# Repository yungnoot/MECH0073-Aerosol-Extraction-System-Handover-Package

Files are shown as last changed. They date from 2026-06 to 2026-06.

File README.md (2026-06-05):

# MECH0073 — Aerosol Extraction System
*MEng Capstone Group Design Project | UCL Mechanical Engineering 2025–2026*
*In collaboration with Agfa Inkjet Solutions, Cambridge*

Industrial inkjet printers eject droplets at high frequency across a millimetre-scale print gap, 
generating fine airborne satellite ink droplets causing a phenomenon known as ink misting. Left unmanaged, these aerosols contaminate machine internals and cause print defects. 

This project develops an aerosol extraction system that selectively captures low-inertia satellite droplets via downstream suction, 
without disturbing primary drop placement.

The design is underpinned by Euler–Lagrange CFD simulations in OpenFOAM, validated against a reduced-scale experimental rig using  shadowgraphy, and realised as a physical prototype compatible with Agfa printers. 

This repository serves as the central handover package for prototype evaluation and future project continuation. The repository for the simulations and custom OpenFOAM solver can be found in https://github.com/Nolanlau/KinematicDualParcelCloud.

## What's in this repo
- `CAD/` — Assembly and part drawings for the experimental rig and extractor prototype
- `Electronics/` — Arduino sensor control code and wiring schematics
- `Documentation/` — Risk assessments, Bill of Materials, Product Design Specification, and end-of-life plan
- `Reports/` — Final project report

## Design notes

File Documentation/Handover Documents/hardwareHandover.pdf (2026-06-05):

# MECH0073 Experimental Rig and Prototype Handover

Nolan Lau Cze Kai | Tengku Amran Sharif | Goh Teik Beng
| Zhou Yuxiang

### 1. Introduction

This document forms the primary handover record for the Aerosol Extraction System project, developed as part of MECH0073 MEng Capstone Group Design Project. The project aimed to computationally and experimentally investigate printzone aerodynamics in industrial inkjet printers, and to design, manufacture, and test an aerosol extraction system compatible with Agfa Inkjet Solutions’ industrial printers. The project consisted of two hardware deliverables:

1. Experimental Rig — A reduced-scale lab rig for validating computational findings via shadowgraphy.
2. Aerosol Extraction System Prototype — A prototype extractor module designed for integration into Agfa industrial inkjet printers.

The next use of the experimental rig is planned for MECH0085 MSc Individual Project (MSc Engineering with Finance, supervised by Prof. José Rafael Castrejón-Pita), in collaboration with a global agricultural technology company, to investigate the effects of Stokes number and droplet deviation from background flow. The prototype extractor module is also to be held by Prof. José Rafael Castrejón-Pita at the Manufacturing Futures Lab at Marshgate, UCL East for use in a future, follow up student project in collaboration with Agfa Inkjet Solutions.

### 2. Physical Items

2.1. Experimental Rig

The following physical components constitute the experimental rig assembly. Full engineering drawings and a detailed Bill of Materials are provided in Appendix C and Appendix B1 of the MECH0073 final report, respectively, and also at our central handover GitHub repository (https://github.com/yungnoot/MECH0073-Aerosol-Extraction-System-Handover-Package) (a QR code is also available at the end of the document). All items are stored in the Manufacturing Futures Laboratory in Marshgate at UCL East under the care of Prof. José Rafael Castrejón-Pita.

2.2. Aerosol Extraction System Prototype

The following physical components constitute the aerosol extraction system prototype. Full engineering drawings and a detailed Bill of Materials are provided in Appendix D and Appendix B2 of the Final Report, respectively and also at our central handover GitHub repository. (https://github.com/yungnoot/MECH0073-Aerosol-Extraction-System-Handover-Package)

1

2 | N. C. K. Lau and T. A. Sharif and T. B. Goh and Y. X. Zhou

Table 1: Experimental Rig Bill of Materials

Item | Description | Qty
Test Rig Experimental Setup | Full assembly | 1
Test Rig Body | Sub-assembly | 1
Test Rig Experimental Mist Capture
Sub-assembly | 1
PLA 3-Way Profile Connector | 3D-printed frame connector | 2
PLA Height Adj. Platform Rod
Holder
3D-printed platform support | 4
Acrylic Height Adj. Platform Base | Adjustable platform | 1
PLA Experimental Nozzle (S0–S4) 3D-printed, five interchangeable geometries | 5
PLA Vacuum Bleed | 3D-printed bleed body | 1
PLA Test Rig Feet | 3D-printed | 4
Acrylic Test Rig Base | Base plate | 1
RS PRO Aluminium | Profile
20×20 mm
Structural frame extrusion | 2

RS PRO Angle Bracket 20×20 mm,
6 mm groove
Frame connector | 8
Stainless Steel Needle Valve | F-to-F with male adaptors, suction control | 1
Airbrush | with | Compressor
(0.3 mm)
Aerosol generation unit | 1
Conveyor Belt | Substrate drive unit | 1
163 cm Camera Tripod | Camera support | 1
Differential Manometer | Testmeter ETI 9202 | 1
Stainless | Steel | Shims
50×50×1 mm
Print-gap height setting | 10
M4×10 Socket Cap Bolt | Standard fastener (ISO 4762) | 20
M4 Flat Washer | Standard fastener (ISO 7089) | 8
M4 Hex Nut | Standard fastener (ISO 4032) | 16

Project Handover | 3

Table 2: Aerosol Extraction System Prototype Bill of Materials

Item | Description | Qty
Prototype Extractor Module Body | Full assembly | 1
Aluminium Extractor External Frame | Machined aluminium structural frame | 1
PLA Extractor Shape Nozzle (S0– S4) | 3D-printed, five interchangeable inlet geome- tries | 5
PLA Locating Block | 3D-printed nozzle guide blocks | 2
Aluminium Vacuum Pump Connec- tor | Machined channel connector | 1
PLA Electronics Housing | 3D-printed enclosure for electronics | 1
Extractor Gasket | Polymer airtight seal between nozzle and frame | 1
Filter Foam | Replaceable filter medium | 1
Sensirion SDP810-500Pa Differen- tial Pressure Sensor | Digital pressure monitoring; upstream and downstream of filter | 2
OLED Display 77×25.2 mm | Sensor readout display | 1
RS PRO Hookup Wire Roll (PVC, 100 m) | Electronics wiring | 1
RS PRO Straight Through-Hole Pin Headers | Electronics connectors | 1
DHT11 Temperature and Humidity Sensor | Ambient condition monitoring | 1
Arduino Uno Rev3 | Microcontroller for sensor data acquisition and display | 1
Flexible Tubing 10 mm OD | Vacuum ducting between extractor and pump | 1
M5×12 Socket Cap Bolt | Standard fastener (ISO 4762) | 10

2.2.1. Unused Materials and Consumables

Any unused materials from the Bills of Materials listed above are stored in the Manufacturing Futures Laboratory at Marshgate, UCL East. Spare items include, but are not limited to:

- Remaining Aluminium Profiles
- Spare OLED monitor
- Remaining flexible tubing
- Remaining RS PRO hookup wire
- Stainless steel shims
2.3. Technical Documentation

The following documentation is included in the handover package. All digital files are accessible via the central handover GitHub repository. (https://github.com/yungnoot/MECH0073-Aerosol-Extraction-System-Handover-Package)

Table 3: Technical Documentation Index

Document | Format | Location / Reference
Final Project Report | PDF | GitHub repository
Engineering Drawings — Ex- perimental Rig | PDF | Appendix C of Final Report, GitHub repository
Engineering Drawings — Aerosol Extraction System | PDF | Appendix D of Final Report, GitHub repository
CAD Files — Experimental Rig | f3d | GitHub repository
CAD Files — Aerosol Extrac- tion System | f3d | GitHub repository
Bill of Materials — Experi- mental Rig | PDF | Appendix B1 of Final Report, GitHub repository
Bill of Materials — Aerosol Extraction System | PDF | Appendix B2 of Final Report, GitHub repository
Arduino Sensor Source Code | .ino | GitHub repository
OpenFOAM CFD Source Code | Text/shell | GitHub repository (with its own handover docu- ment and documentation repository).
Risk Assessments | PDF | Appendix A of Final Report, OSHENS risk man- agement system, GitHub repository
Experimental Results | jpg/mp4 | GitHub repository

### 3. Operating Instructions

3.1. Experimental Rig Setup
1. Assemble the aluminium profile frame using the 3-way connectors and angle brackets; tighten M4 socket cap bolts finger-tight before final torque.
2. Install the acrylic base and height adjustable platform. Set the print gap height as desired using precision shims placed at multiple spanwise locations. Secure the acrylic ceiling via bolts on the platform rods.
3. Mount the airbrush nozzle flush with the underside of the acrylic ceiling sheet, oriented perpendicular to the substrate, using the retort stand. Fix the nozzle at the print gap centreline.
4. Insert the desired extractor nozzle geometry into the dedicated slot in the downstream acrylic panel.
5. Connect the vacuum cleaner to the bleed body with needle valve in line to regulate suction pressure.
6. Connect the differential manometer to the pressure tap on the extractor body to monitor suction gauge pressure.
7. Start the conveyor belt and allow it to reach steady state before data acquisition. The conveyor is operated at the maximum drive setting throughout all tests.
8. Activate the airbrush compressor. The airbrush spray force should be approximately 21.58 mN, as measured previously via precision scale.
9. Illuminate the printzone using the high-power lighting positioned to maximise contrast for shadowgraphy.
10. Experiments can be recorded by mounting an available camera on the tripod.

Safety: Always turn off the conveyor belt and vacuum when adjusting the extractor or airbrush position. Wear ear protection during prolonged operation. Refer to the MechSpace Risk Assessment (Appendix A2) if uncertain about operational risks before first use.

3.2. Aerosol Extraction System Prototype — Assembly and Integration
1. Slot the desired inlet nozzle piece (S1–S4) into the base of the aluminium frame using the two PLA locating blocks as guides, and bolt into the frame using M3×12 socket cap bolts.
2. Seat filter foam or other filter medium on the interface between the frame and the vacuum pump connector.
3. Bolt the aluminium vacuum pump connector onto the top face of the aluminium frame using M5×12 socket cap bolts.
4. Electronic sensor box comes pre-assembled, but can be easily unbolted to make modifications.
5. Attach the 10mm OD pneumatic tubing from the sensor box into the hole insert in the static fixed jaw, and the 4mm OD into the tap sitting perpendicular on the face of the vacuum connector.
6. Connect the vacuum cleaner to vacuum pump connector, using PVC piping as necessary to extend length as desired.
7. Power electronic sensor box using an appropriate power supply with the provided USB-B to USB-A cable.

### 4. End-of-Life Plan

4.1. Experimental Rig

The experimental rig will be retained at Marshgate, UCL East and reused in the following academic year for MECH0085 MSc Individual Project, supervised by Prof. Castrejón-Pita, in collaboration with a global agricultural technology company. All PLA components are reprintable from the CAD files provided in the GitHub repository should replacement parts be required. Aluminium profile sections and acrylic panels should be stored flat and protected from impact damage.

4.2. Aerosol Extraction System Prototype

The aerosol extraction system prototype will be retained at Marshgate, UCL East for future student projects in collaboration with Agfa Inkjet Solutions. Transfer of prototype has been organised with Prof. Castrejón-Pita to be moved to the Manufacturing Futures Laboratory at Marshgate, UCL East after the 2026 Mechanical Engineering Summer Session. The Open-FOAM computational model is available on GitHub for use in future student projects, and comes with a separate handover document as part of the handover package.

4.3. Disposal of Materials
- PLA offcuts and failed prints are disposed of in the PLA recycling bin on the 5th Floor workshop inside MechSpace.
- Acrylic sheets that are unsuitable for reuse are disposed of in the appropriate recycling bins.

### 5. Key Contacts

For queries relating to the project, rig, or prototype, contact the relevant parties listed below.

Table 4: Key Project Contacts

Role | Name | Contact
Project Supervisor | Prof. | José | Rafael
Castrejón-Pita

r.pita@ucl.ac.uk

Team Member | Teik Beng Goh | derrick.goh.22@alumni.ucl.ac.uk
Team Member | Nolan Lau Cze Kai | nolan.lau.22@alumni.ucl.ac.uk
Team Member | Tengku Amran Sharif | amran.sadruddin.22@alumni.ucl.ac.uk
Team Member | Yuxiang Zhou | yuxiang.zhou.22@alumni.ucl.ac.uk

### 6. Declarations

This handover document has been prepared by the Aerosol Extraction System group as a component of the MECH0073 prototype handover package. The team confirms that:

- All physical items listed in Section 2 are present and accounted for in the designated storage space provided by Prof. José Rafael Castrejón-Pita at the Manufacturing Futures Laboratory at Marshgate, UCL East.
- All documentation listed in Section 2.3 has been submitted and is accessible via the project GitHub repository.
- All risk assessments are fully signed off and available in Appendix A of the Final Report, on the OSHENS risk management system, and the central GitHub repository accessible via QR code below.

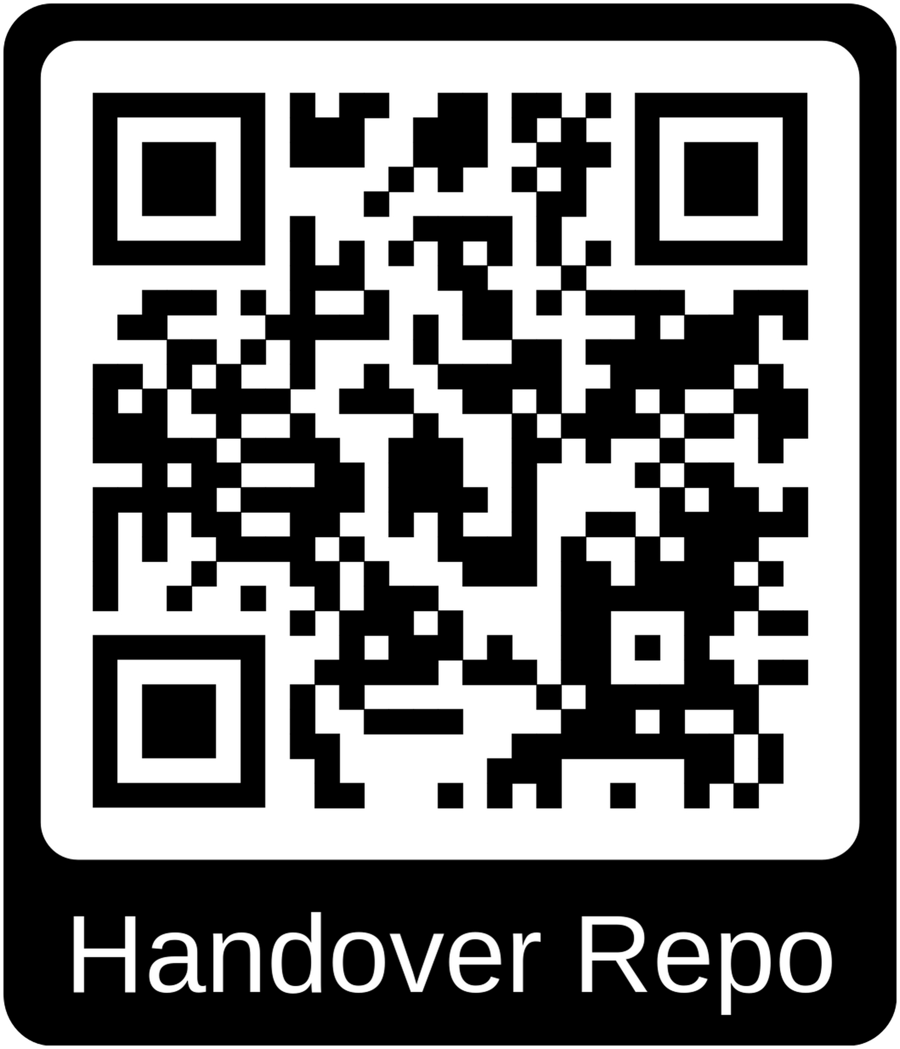
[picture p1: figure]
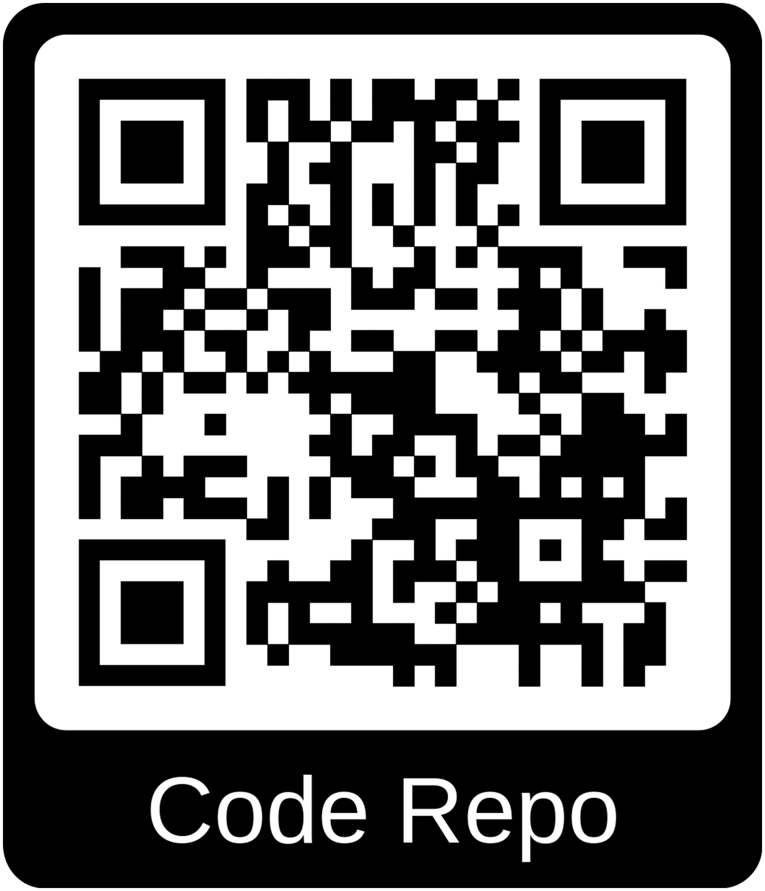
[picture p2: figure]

Figure 1: Handover Repository QR Code | Figure 2: Code Repository QR Code

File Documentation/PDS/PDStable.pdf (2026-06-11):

Table 1: Product design specification for the aerosol extraction system prototype framed as Functions, Objectives, and Constraints (FOC) (extracted from final report).

Category | Requirement | Specification
Functions | Mist Extraction | • Remove airborne low-inertia satellite droplets and ink mist from the printzone during operation via downstream suction.
| Selective Action | • Preferentially entrain low-inertia satellite droplets while leaving the trajectories of the main printing droplets ef- fectively unchanged.
| Continuous Operation | • Operate continuously over typical industrial print dura- tions without loss of basic functionality.
| Flow Regulation | • Allow for the adjustment of suction pressure to tune for specific situations, accompanied by active differential pressure measurement.
| Condition Monitoring | • Monitor ambient temperature and relative humidity for experimental characterisation, and provide indicators of degraded operating conditions (e.g., pressure changes due to filter loading).
Objectives | Extraction Efficiency | • Achieve a high capture rate of airborne mist-forming satellites, targeting a 50% capture rate corresponding to 20 g/s. • Actual performance can be gauged by the darkening of a HEPA filter.
| Suction Strength | • Minimise pressure drop or losses across the system to ensure operating efficiency.
| Maintainability | • Provide straightforward access for the cleaning of de- posited ink and the rapid replacement of filters or in- ternal flow components.
| Assembly Simplicity | • Minimise the number of parts with interchangeable parts, enabling straightforward assembly and installation using simple fasteners (e.g., bolts).
| Manufacture Simplicity | • The design should be easily manufactured using access- ible methods like additive manufacturing, machining and standard workshop fabrication.
| Modularity | • Ensure design elements (e.g., extractor geometry, elec- tronics) are easily swappable and expandable to allow for rapid iteration and future improvements.

1

Table 1: Product design specification for the aerosol extraction system prototype framed as Functions, Objectives, and Constraints (continued).

Category | Requirement | Specification
Constraints | Geometric
Limits
- The system must conform to a maximum bounding box of 770 mm × 170 mm × 750 mm (free space available in printers).

Spatial
Compatibility
- The extractor must maintain clearance for the printgap and absolutely must not obstruct printheads, sensors, maintenance access points, or other critical printer subsystems.
Capture Zone | • The extractor inlet geometry must possess a sufficiently
large capture zone of 350 mm in length to cover the working area of the printhead.

Material
Integrity
- Materials must be sufficiently stiff to maintain alignment and stability during operation.
- Prolonged exposure to inks must not lead to significant chemical degradation (though superficial aesthetic staining is acceptable).

Electrical Safety • Any electronics used for sensing or monitoring must operate safely at low voltages and be suitable for safe integration into a prototype system.

2

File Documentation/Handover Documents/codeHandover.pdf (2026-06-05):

# Conducting Euler-Lagrange Particle Coupled Fluid Dynamics Simulations on OpenFOAM

Nolan Lau Cze Kai | Tengku Amran Sharif | Goh Teik Beng
| Zhou Yuxiang

### 1. Introduction

Our simulations involved simulating inkjet printing which involved ejected ink particles moving within air. This is a multiphase situation due to the liquid and gas phase involved. Our approach leveraged on the assumption that as the inks are water-based, the capillary length in air would be approximately 2.7 mm (Rapp, 2017), and thus much larger than the droplet diameters which are of μm size. This allowed us to assume that the ink droplets behaved as rigid spheres in air, adopting a Lagrangian approach for the ink droplets. We conducted our simulations in OpenFOAM (Weller et al., 1998). Due to our specific requirements, a proprietary solver coined as kinematicDualParcelFoam was programmed and used and is publicly accessible on GitHub (https://github.com/Nolanlau/KinematicDualParcelCloud) (Lau, 2026). The GitHub also includes an example case for reference. This document will be primarily based on the use of the aforementioned solver. Use of the solver expects experience and understanding in computational fluid dynamics (CFD) and is far beyond the scope of someone who has only followed a guided tutorial before.

### 2. Hardware and Software Prerequisites

The computationally demanding nature of computational fluid dynamics (CFD) simulations necessitates suitable computational hardware other than for small validation cases. As a minimum recommendation, local execution should employ:

1. a modern multi-core CPU (preferably ≥ 8 physical cores),
2. at least 16–32 GB RAM,
3. and a solid-state drive (SSD).

The simulations are predominantly CPU-bound rather than GPU-bound, as OpenFOAM does not natively exploit GPU acceleration in standard configurations. Furthermore, OpenFOAM works only in Linux environments.
The recommended execution environments are therefore:
1. Windows Subsystem for Linux (WSL2) on Windows,
2. UCL Kathleen HPC Cluster,
3. UCL Myriad HPC Cluster.

The UCL high performance computing (HPC) clusters are especially recommended for bulk work particularly UCL Kathleen HPC Cluster (https://www.rc.ucl.ac.uk/docs/Clusters/Kathleen/) and UCL Myriad HPC Cluster. (https://www.rc.ucl.ac.uk/docs/Clusters/Myriad/) Students can apply for access with the sponsorship of a permanent staff.

1

2 | N. C. K. Lau and T. A. Sharif and T. B. Goh and Y. X. Zhou
2.1. OpenFOAM Environment

The simulations are conducted using OpenFOAM, an open-source finite volume CFD framework written primarily for Linux-based operating systems. OpenFOAM is not natively supported under standard Windows environments and therefore requires either:

1. a Linux operating system (including through a virtual machine),
2. Windows Subsystem for Linux (WSL2),
3. or execution through a remote Linux HPC cluster (e.g., UCL Myriad).
| The recommended OpenFOAM version for this project is OpenFOAM® v2112 as the
custom solver was developed for this release. We have found OpenFOAM® v2312 to work as well. Compatibility with older versions is poor but newer versions are likely to work. If installing on a private system, the installation guide (https://gitlab.com/openfoam/core/openfoam/-/wikis/precompiled) should be consulted. UCL Myriad and Kathleen already carry several versions of OpenFOAM.
| The OpenFOAM tutorial cases distributed with the software as well as additional docu-
mentation online are highly recommended for familiarisation with:
1. theoretical basis of finite volume method (FVM)
2. mesh generation,
3. solver execution,
4. multiphase flow,
5. and lagrangian particle tracking.
2.1.1. Local Installation Using WSL2

For users operating on Windows systems, the recommended approach is to install Ubuntu Linux through Windows Subsystem for Linux 2 (WSL2). This provides a near-native Linux environment while retaining standard Windows usability. Microsoft provides installation instructions. (https://learn.microsoft.com/en-us/windows/wsl/install)
| Ubuntu 22.04 LTS is recommended for compatibility with OpenFOAM-v2212. General
Linux familiarity, including use of the shell, bash scripting, SSH and file permissions is assumed for effective use of OpenFOAM and the HPC clusters.
| You should be highly familiar with the use of OpenFOAM before proceeding further.

Euler-Lagrange Particle Coupled Simulations Fluid Dynamics | 3

### 3. Solver kinematicDualParcelFoam

The custom solver kinematicDualParcelFoam was adapted from the standard OpenFOAM solver kinematicParcelFoam and shares close similarities. The main difference is that within the functional class of cloud, the base solver, kinematicParcelFoam only has a singular cloud (kinematicDualParcelFoam) whereas the custom solver has two (mainCloud and satelliteCloud). This allows for the simultaneous evolutions of two different types of particles which may have different properties in a single simulation.

3.1. Governing Equations

The computational model adopts an Euler–Lagrange formulation. The carrier phase, namely air, is treated as a continuum and solved on an Eulerian mesh, while droplets are tracked as discrete Lagrangian particles. This approach is well suited to particle-laden flows in which the dispersed phase occupies a small volume fraction but may still exchange momentum with the carrier phase.
The carrier phase is treated as an incompressible Newtonian fluid with the incompressible Navier-Stokes equation solved in the Eulerian frame as
∇ ⋅ u = 0, | (1)

Du
Dt

= −

1
ρ
∇p + ν∇²u + S, | (2)

where u represents fluid velocity, p is pressure, ρ and ν are the fluid density and kinematic viscosity respectively. The source term, S represents the momentum coupling from the Lagrangian phase, accounting for the impulse transfer from the particles to the fluid. The translational motion of the spherical particles are described by the trajectory equation and Newton’s Second Law,
dxP
dt
= uP, | (3)

mP

duP
dt

= Fd + Fg

, | (4)

where xP and uP represent the position and velocity of the particle respectively while the particle mass is calculated as

mP = ρP

πD³
P
6
, | (5)

being a uniform sphere, where ρP represents the particle density and DP is the particle diameter. The drag force term Fd
is calculated using the sphere drag correlations by Putnam (1961) as

Fd = Cd

πD²
P
8
ρ(u − uP)|u − uP|, | (6)

where the drag coefficient, Cd

is calculated using the local particle Reynolds number, ReP as
Cd = { ²⁴
ReP

(1 + 1

6Re²/3
P

) if ReP ≤ 1000
0.424 | if ReP > 1000
. | (7)

The gravity force term is calculated as

Fg = mPg (1 − ρ
ρP
) , | (8)

where g is the gravitational acceleration vector.
For the present application, additional force contributions such as virtual mass and pressuregradient effects are small in comparison with drag and gravity and are therefore neglected. However, additional forces may be customised or enabled in the simulation to change (4) as desired. The Euler–Lagrange framework is particularly useful because it permits direct modelling of the force coupling between primary droplets and the carrier flow, while also allowing a large population of secondary droplets to be tracked efficiently.
3.2. Compilation Instructions

The custom solver can be compiled and installed to your version of OpenFOAM using the instructions in the GitHub. (https://github.com/Nolanlau/KinematicDualParcelCloud/blob/main/README.md) However, the OpenFOAM base files are not modifiable in the UCL HPC. Instead, the solver will have to be compiled within your scratch and invoked through its path on scratch.

### 4. Running Simulations

This section describes the general workflow for preparing and executing simulations using the custom kinematicDualParcelFoam solver. The workflow consists broadly of:

1. mesh generation,
2. configuration of the Eulerian flow solver,
3. configuration of the Lagrangian particle clouds,
4. parallel decomposition,
5. solver execution,
6. and post-processing.

In the OpenFOAM idiom, a simulation is enclosed within a case which is a folder consisting of settings and where results will be stored upon execution. An example case using the solver is provided within the GitHub. (https://github.com/Nolanlau/KinematicDualParcelCloud)

4.1. Case Structure

OpenFOAM cases generally follow the directory structure:

case/
0/
constant/
system/

The purpose of each directory is:

1. 0/: Initial and boundary conditions,
2. constant/: Mesh, material properties, and cloud settings,
3. system/: Numerical schemes and solver controls.

4.2. Mesh Generation

The computational mesh is generated prior to simulation execution. The example case within the GitHub (https://github.com/Nolanlau/KinematicDualParcelCloud) contains a functioning mesh. When creating a mesh for your specific purposes, to ensure highly reproducible and iterative workflows, we suggest the use of parametric mesh generation scripts written in MATLAB (or other programming language).

4.2.1. Parametric blockMeshDict Generation

For simple block-structured geometries, OpenFOAM employs the blockMesh utility. Its configuration is natively defined in a dictionary within system/blockMeshDict. For small changes from the mesh provided in the example case, the corresponding blockMeshDict may be manually modified. For more extensive studies, we recommend the use of a MAT-LAB script to parametrically write the blockMeshDict dictionary file so that the geometric properties can be easily changed. Once the MATLAB script writes the blockMeshDict to the system/ directory, the mesh is generated natively in OpenFOAM by running:

blockMesh

4.2.2. Parametric Gmsh Mesh Generation

For more complex geometries (e.g., non-orthogonal or spline boundaries), we recommend the use of Gmsh (https://gmsh.info/) for the creation of unstructured meshes (Geuzaine & Remacle, 2009). A similar script should be used to write a dictionary ’.geo’ file. We then execute Gmsh from the terminal to create a 3D mesh exported in the ‘.msh‘ format:

gmsh -3 <name>.geo -format msh2

Finally, the mesh is converted to OpenFOAM format via the built-in utility:

gmshToFoam <name>.msh

Regardless of the approach employed (native blockMesh or Gmsh), the computational mesh quality should subsequently be verified using:

checkMesh

for low mesh non-orthogonality particularly if complex geometry is involved.

4.3. Initial and Boundary Conditions

The initial and boundary conditions are specified within the 0/ directory. Common files include:

0/U
0/p

The velocity field file (U) specifies velocity boundary conditions and the initial field. It will come to taken on the global velocity field in later time steps. The moving substrate is typically implemented using a Dirichlet boundary condition

type | fixedValue;
value | uniform ( 1 0 0 );

while inlets and outlets take on

type | zeroGradient;

and walls take on the no slip condition as

type | noSlip;

The pressure field file (p) specifies pressure boundary conditions. Inlets and outlets have their pressures specified as desired. Atmospheric boundaries are specifically specified as zero gauge pressure as

type | fixedValue;
value | uniform 0;

while walls have

type | zeroGradient;
4.4. Lagrangian Particle Clouds

The custom solver supports two particle clouds:

1. a coupled primary cloud,
2. and an uncoupled secondary cloud.

The primary cloud represents the larger ballistic droplets responsible for printing and exchanges momentum with the carrier phase. The secondary cloud represents smaller satellite droplets which behave approximately as passive tracers and do not contribute appreciably to the momentum source term.
Cloud properties are generally specified within:

constant/
mainCloudProperties
satelliteCloudProperties

or equivalent cloud configuration dictionaries. Typical parameters include:

1. particle diameter,
2. density,
3. injection velocity,
4. parcel count,

5. injection location,
6. drag law,
7. and interaction models.

A simplified example is:

solution
{
active | yes;
coupled | yes;
transient | yes;
}

constantProperties
{
rho0 | 1000;
}

subModels
{
particleForces
{
sphereDrag;
}

injectionModels
{
model1
{
type | patchInjection;
patchName | nozzlePatch;
U0 | (0 -10 0);
parcelsPerSecond 100000;
duration | 1;
flowRateProfile constant 1; sizeDistribution
{
type fixedValue;
fixedValueDistribution
{
value 22e-6;
}
}
}
}

}

Note that the secondary cloud, satelliteCloud does not contribute a source term to the momentum equation in (2) so toggling

coupled no;

is redundant. However, the solver could be modified to have both clouds contributing momentum source terms whereupon they could be separately toggled on and off.

4.5. Numerical Controls

The primary numerical controls are contained within:

system/controlDict
system/fvSchemes
system/fvSolution

The timestep is constrained using the Courant number:

adjustTimeStep yes;
maxCo | 0.5;

Transient simulations involving particle injection generally require small timesteps owing to high particle velocities and small mesh scales. Furthermore, OpenFOAM only natively supports first-order Euler method time-stepping for particle motion.

4.6. Running Simulations Locally

After mesh generation and case setup, the simulation may be executed serially using:

kinematicDualParcelFoam

For parallel execution using 8 cores:

decomposePar
mpirun -np 8 kinematicDualParcelFoam -parallel

After completion:

reconstructPar

The decomposition settings are specified in:

system/decomposeParDict

An example configuration for decomposition into 8 subdomain for 8 cores is:

numberOfSubdomains 8;

method scotch;

4.7. Running Simulations on UCL HPC Clusters

Large simulations should be executed through the UCL HPC batch scheduling system. Before execution, the appropriate software environment must be loaded:

module load beta-modules
module unload gcc-libs
module load gcc-libs/7.3.0
module unload compilers
module load compilers/gnu/7.3.0
module unload mpi
module load mpi/openmpi/3.1.4/gnu-7.3.0 module load openfoamplus/v2112/gnu-7.3.0-64

A typical submission script is shown below.

4.7.1. Example HPC Submission Script

#!/bin/bash -l

#$ -S /bin/bash

#$ -l h_rt=24:00:0

#$ -l mem=1G

#$ -N test

#$ -pe mpi 7

#$ -wd /myriadfs/home/<user>/Scratch/test

module load beta-modules

module unload gcc-libs
module load gcc-libs/7.3.0

module unload compilers
module load compilers/gnu/7.3.0

module unload mpi
module load mpi/openmpi/3.1.4/gnu-7.3.0

module load openfoamplus/v2112/gnu-7.3.0-64

source $WM_PROJECT_DIR/etc/bashrc

blockMesh

decomposePar -force

gerun \
/myriadfs/home/<userID>/Scratch/kinematicDualParcelFoam/kinematicDualParcelFoam \ -parallel
reconstructPar

10 | N. C. K. Lau and T. A. Sharif and T. B. Goh and Y. X. Zhou

rm -r processor*

4.8. Submitting Jobs

The script may be submitted using:

| qsub submit.sh
| Job status may be monitored using:

qstat

| A job may be terminated with:
| qdel <jobID>
4.9. Post-Processing

Simulation results may be visualised using ParaView:

paraFoam

Note that while 3D visualisation is supposedly possible using UCL HPC Clusters with an X server, we have found this unreliable. We recommend doing 3D post-processing with ParaView locally on your personal computer.

References

Geuzaine, C., & Remacle, J.-F. (2009). Gmsh: A 3-D finite element mesh generator with built-
| in pre- and post-processing facilities. International Journal for Numerical Methods in Engineering, 79(11), 1309–1331. https://doi.org/10.1002/nme.2579

Lau, N. C. K. (2026). kinematicDualParcelFoam. Retrieved February 7, 2026, from https:
| //github.com/Nolanlau/KinematicDualParcelCloud/tree/main
Putnam, A. (1961). Integratable form of droplet drag coefficient. Journal of the American
| Rocket Society, 31(10), 1467–1468.
Rapp, B. E. (2017). Chapter 21 - capillarity. In B. E. Rapp (Ed.), Microfluidics: Modelling,
| Mechanics and Mathematics (pp. 445–451). Elsevier. https://doi.org/10.1016/B978- 1-4557-3141-1.50021-6 (https://doi.org/10.1016/B978-1-4557-3141-1.50021-6)

Weller, H. G., Tabor, G., Jasak, H., & Fureby, C. (1998). A tensorial approach to computa-
| tional continuum mechanics using object-oriented techniques. Computer in Physics, 12(6), 620–631. https://doi.org/10.1063/1.168744

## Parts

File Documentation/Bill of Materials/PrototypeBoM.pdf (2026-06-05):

# BILL OF MATERIALS

PROJECT REF: | 547908
Project | Bom Section | UID | Issue Revision | Type | Part Description | Part Number | Quantity | Layout | 3D | 2D | Density Mass Each
547908 | 00 | 0000 | 01 | B | Assembly | Prototype Extractor Module Body | 547908-00-0000-01B | 1 | g | g | g | 0 | 0.000
547909 | 01 | 0001 | 01 | A | Assembly | Extractor Electronic Integration | 547909-01-0001-01A | 1 | g | g | g
547908 | 02 | 0002 | 01 | A | Assembly | Video/Image Recording Setup | 547908-02-0002-01A | 1 | g | g | g | 0
547908 | 00 | 0003 | 01 | B | Part | Aluminium Extractor External Frame | 547908-00-0003-01B | 1 | g | g | g | 2700 | 1.264
547908 | 00 | 0004 | 01 | B | Part | PLA Extractor Shape Nozzle | 547908-00-0004-01B | 5 | g | g | g | 1250 | 0.878
547908 | 00 | 0005 | 01 | A | Part | PLA Locating Block | 547908-00-0005-01A | 2 | g | g | g | 1250 | 0.078
547908 | 00 | 0006 | 01 | A | Part | Aluminium Mounting Bracket | 547908-00-0006-01A | 2 | g | g | g | 2700 | 0.105
547908 | 00 | 0007 | 01 | A | Part | Aluminium Extractor Vacuum Connector | 547908-00-0007-01A | 1 | g | g | g | 1250 | 0.273
547908 | 01 | 0008 | 01 | A | Part | PLA Electronics Housing | 547908-01-0008-01A | 1 | g | g | g | 1250 | 0.086
547908 | 01 | 0009 | 01 | A | Part | Alumnium Electronics Housing Bracket | 547908-01-0009-01A | 2 | g | g | g | 2700 | 0.003
547908 | 00 | 0010 | 01 | A | Part | Extractor Gasket | 547908-00-0010-01A | 1 | g | g | g | 1380 | 0.391
547908 | 00 | 0011 | 01 | A | Procurement 300 x 1200 mm PM2.5 HEPA Filter Paper with 20 mm Folds | 547908-00-0011-01A | 1 | G | g | g | 0 | 0.040
547908 | 01 | 0012 | 01 | A | Procurement Sensiron Pressure sensor (+- 500Pa) | 547908-01-0012-01A | 2 | g | g | g | 0 | 0.000
547908 | 01 | 0013 | 01 | A | Procurement 2.42 Inch SSD1309 128 x 64 OLED Display | 547908-01-0013-01A | 1 | g | g | g | 0 | 0.015
547908 | 01 | 0014 | 01 | A | Procurement RS PRO PVC 100m Hookup Wire Roll | 547908-01-0014-01A | 0.01 | g | g | g | 0 | 0.060
547908 | 01 | 0015 | 01 | A | Procurement RS PRO Straight Through Hole Pin Headers | 547908-01-0015-01A | 1 | g | g | g | 0 | 0.022
547908 | 01 | 0016 | 01 | A | Procurement DHT11 Module (Temperature and Humidity sensor) | 547908-01-0016-01A | 1 | g | g | g | 0 | 1.000
547908 | 01 | 0017 | 01 | A | Procurement Arduino UNO Rev 3 | 547908-01-0017-01A | 1 | g | g | g | 0 | 0.004
547908 | 02 | 0018 | 01 | A | Procurement 163cm Camera Tripod | 547908-02-0018-01A | 1 | g | g | g | n | 1.150
547908 | 00 | 0019 | 01 | A | Procurement RS PRO Polyvinyl Chloride Flexible Tubing 6mm OD | 547908-00-0019-01A | 1 | g | g | g | 1300 | 0.600
547908 | 05 | 0020 | 01 | A | Procurement 8 Channel Expansion Board | 547908-05-0020-01A | 1 | g | g | g | n | 0.005
547908 | 05 | 0021 | 01 | - | Standard Part Solderable Breadboard | 547908-05-0021-01- | 2 | g | g | g | n | 0.001
547908 | 05 | 0022 | 01 | - | Standard Part USB A to B Cable | 547908-05-0022-01- | 1 | g | g | g | n | 0.100
547908 | 05 | ISO 4762 | - | - | Standard Part M4x20 Socket Cap Bolt | 547908-05-ISO 4762--- | 12 | g | g | g | 7900 | 0.003
547908 | 05 | ISO 4762 | - | - | Standard Part M5x20 Socket Cap Bolt | 547908-05-ISO 4762--- | 12 | g | g | g | 7900 | 0.004
547908 | 05 | ISO 7089 | - | - | Standard Part M4 Flat Washers | 547908-05-ISO 7089--- | 12 | g | g | g | 7900 | 0.000
547908 | 05 | ISO 7089 | - | - | Standard Part M5 Flat Washers | 547908-05-ISO 7089--- | 12 | g | g | g | 7900 | 0.000
547908 | 05 | ISO 4762 | - | - | Standard Part M10 Socket Cap Bolt | 547908-05-ISO 4762--- | 4 | g | g | g | 7900 | 0.023
| | | | | | | | | | | | | Total Mass
Part/Item Identification | Design Stage | Mass (kg)

Mass
Total
0.000 | - £ | - £ | N/A
N/A
0.000 N/A
1.264 | 12.64 £ | 12.64 £ | Agfa | Material sponsored by Agfa, cost taken as online estimate
4.390 | 0.88 £ | 4.39 £ | N/A | Printed in MechSpace
0.156 | 0.08 £ | 0.16 £ | N/A | Printed in MechSpace
0.210 | 0.11 £ | 0.21 £ | Agfa | Material sponsored by Agfa
0.273 | 0.27 £ | 0.27 £ | Agfa | Material sponsored by Agfa
0.086 | 0.09 £ | 0.09 £ | N/A | Printed in MechSpace
0.005 | 0.00 £ | 0.01 £ | Agfa | Material sponsored by Agfa
0.391 | 0.78 £ | 0.78 £ | Agfa | Material sponsored by Agfa
0.040 | 1.24 £ | 1.24 £ | AliExpress | https://www.aliexpress.com/item/1005005861215996.html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 2W
0.000 | 22.04 £ | 44.09 £ | RS | 133-1913 | https://uk.rs-online.com/web/p/pressure-sensor-ics/1331913 3D
0.015 | 12.99 £ | 12.99 £ | Amazon | https://www.amazon.co.uk/dp/B0GCJ177JF?ref_=ppx_printOD_title_mob_ap_fed_asin_title_0_1 1D
0.001 | 39.30 £ | 0.39 £ | RS | 183-9225 | https://uk.rs-online.com/web/p/hook-up-wire/1839225 3D
0.022 | 7.58 £ | 7.58 £ | RS | 251-8632 | https://uk.rs-online.com/web/p/pcb-headers/2518632 3D
1.000 | 7.12 £ | 7.12 £ | RS | 216-3753 | https://uk.rs-online.com/web/p/arduino-compatible-boards-kits/2163753 3D
0.004 | 22.34 £ | 22.34 £ | RS | 715-4081 | https://uk.rs-online.com/web/p/arduino/7154081?gb=a 3D
1.150 | - £ | £ | - | Amazon | https://www.amazon.co.uk/dp/B0B1HYVVTV?ref_=cm_sw_r_cso_cp_apan_dp_QR3R8SD4C7YKECBHRRJK 4D
0.600 | 12.06 £ | 12.06 £ | Agfa | 336-821 | https://uk.rs-online.com/web/p/hose-pipe-flexible-tubes/0336821 3D | Material sponsored by Agfa
0.005 | 3.99 £ | 3.99 £ | Amazon
0.002 | 1.32 £ | 2.64 £ | RS | 286-2016 | https://uk.rs-online.com/web/p/breadboards/2862016 3D
0.100 | 3.35 £ | 3.35 £ | RS | 236-9076 | https://uk.rs-online.com/web/p/usb-cables/2369076 3D
0.032 | 0.04 £ | 0.48 £ | N/A | Supplied from MechSpace
0.048 | 0.30 £ | 3.60 £ | N/A | Supplied from MechSpace
0.004 | 0.02 £ | 0.24 £ | N/A | Supplied from MechSpace
0.005 | 0.02 £ | 0.24 £ | N/A | Supplied from MechSpace
0.092 | 0.24 £ | 0.96 £ | N/A | Supplied by Agfa
9.895 | Total Cost | £ | 141.85
Cost Details (₤) | Supply Chain Management
Cost Each Cost Total (inc. VAT) (inc. VAT) | Company | Supplier Part Number Hyperlink Lead Time | Additional Info

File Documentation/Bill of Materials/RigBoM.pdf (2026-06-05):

# BILL OF MATERIALS

PROJECT REF: | 547908
547908 | 00 | 0001 | 03 | C | Assembly | Test Rig Experimental Setup | 547908-00-0001-03C | 1 | g | g | g | 0 | 0.000 | £ | - | £ | - | N/A
547908 | 01 | 0002 | 03 | C | Assembly | Test Rig Body | 547908-01-0002-03C | 1 | g | g | g | 0 | 0.000 | £ | - | £ | - | N/A
547908 | 02 | 0003 | 03 | C | Assembly | Test Rig Experimental Mist Capture | 547908-02-0003-03C | 1 | g | g | g | 0 | 0.000 | 0.000 | £ | - | £ | - | N/A
547908 | 03 | 0004 | 01 | A | Assembly | Video/Image Recording Setup | 547908-03-0004-01A | 1 | g | g | g | 0 | | 0.000 | | | | N/A
547908 | 01 | 0005 | 01 | B | Part | PLA 3-Way Profile Connector | 547908-01-0005-01B | 2 | g | g | g | 1250 | 0.001 | 0.001 | £ | 0.05 £ | 0.10 | N/A | Printed in MechSpace
547908 | 01 | 0006 | 01 | A | Part | PLA Height Adjustable Platform Rod Holder | 547908-01-0006-01A | 4 | g | g | g | 1250 | 0.003 | 0.010 | £ | 0.15 £ | 0.60 | N/A | Printed in MechSpace
547908 | 01 | 0007 | 01 | C | Part | Acrylic Height Adjustable Platform Base | 547908-01-0007-01C | 1 | g | g | g | 1190 | 0.327 | 0.327 | £ | 8.18 £ | 8.18 | N/A | Printed in MechSpace
547908 | 02 | 0008 | 01 | C | Part | PLA Experimental Nozzle | 547908-02-0008-01C | 5 | g | g | g | 1250 | 0.028 | 0.139 | £ | 1.40 £ | 7.00 | N/A | Printed in MechSpace
547908 | 02 | 0009 | 02 | B | Part | PLA Vacuum Bleed | 547908-02-0009-02B | 1 | g | g | g | 1250 | 0.056 | 0.056 | £ | 2.80 £ | 2.80 | N/A | Printed in MechSpace
547908 | 01 | 0010 | 01 | A | Part | PLA Test Rig Feet | 547908-01-0010-01A | 4 | g | g | g | 1250 | 0.007 | 0.028 | £ | 0.35 £ | 1.40 | N/A | Printed in MechSpace
547908 | 01 | 0011 | 01 | A | Part | Acrylic Test Rig Base | 547908-01-0011-01A | 1 | g | g | g | 1250 | 0.291 | 0.291 | £ | 7.27 £ | 7.27 | N/A | Material sponsored by Agfa
547908 | 01 | 0012 | 01 | A | Procurement | RS PRO 20x20mm Aluminium Profile | 547908-01-0012-01A | 2 | g | g | g | 2700 | 0.842 | 1.684 | £ | 19.31 £ | 38.62 | RS | 850-8489 | https://uk.rs-online.com/web/p/tubing-and-profile-struts/8508489 1D
547908 | 01 | 0013 | 01 | A | Procurement | RS PRO Angle Bracket, 20x20 mm Profile, 6mm Groove | 547908-01-0013-01A | 8 | g | g | g | 7900 | 0.007 | 0.056 | £ | 0.79 £ | 6.29 | RS | 180-9137 | https://uk.rs-online.com/web/p/connecting-components/1809137?gb=a 1D
547908 | 02 | 0014 | 01 | A | Procurement | Stainless Steel Needle Valve F to F with Male Adaptors | 547908-02-0014-01A | 1 | g | g | g | 7900 | 0.250 | 0.250 | £ | 18.99 £ | 18.99 | Amazon | | https://www.amazon.co.uk/dp/B0F1D16MLW 4D
547908 | 00 | 0015 | 01 | A | Procurement | Airbrush with Compressor 0.3mm | 547908-00-0015-01A | 1 | g | g | g | 0 | 1.200 | 1.200 | £ | 34.99 £ | 34.99 | AliExpress | | https://www.aliexpress.com/item/1005005248568835.html?spm=a2g0o.order_list.order_list_main.11.936018029vTVvw 2W
547908 | 00 | 0016 | 01 | A | Procurement | Dry-Wet Vacuum Cleaner 15L | 547908-00-0016-01A | 1 | g | g | g | 0 | 4.450 | 4.450 | £ | 30.59 £ | 30.59 | AliExpress | | https://www.aliexpress.com/item/1005007341056091.html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 2W
547908 | 00 | 0017 | 01 | A | Procurement | Conveyor Belt, 610 x 155 x 75 mm | 547908-00-0017-01A | 1 | g | g | g | 0 | 2.500 | 2.500 | £ | 88.98 £ | 88.98 | AliExpress | DCODE 60CM MINI | https://www.aliexpress.com/item/1005007273740659.html?spm=a2g0o.order_list.order_list_main.5.553318021K8mal 3W5D
547908 | 03 | 0018 | 01 | A | Procurement | 163cm Camera Tripod | 547908-03-0018-01A | 1 | g | g | g | 0 | 1.150 | 1.150 | £ | 45.99 £ | 45.99 | Amazon | | https://www.amazon.co.uk/dp/B0B1HYVVTV?ref_=cm_sw_r_cso_cp_apan_dp_QR3R8SD4C7YKECBHRRJK 4D
547908 | 02 | 0019 | 01 | A | Procurement | Differential Manometer | 547908-02-0019-01A | 1 | g | g | g | 0 | 0.185 | 0.185 | £ | 96.00 £ | 96.00 | Testmeter | ETI9202 | https://www.test-meter.co.uk/eti-9202-differential-manometer 1W
547908 | 04 | 0020 | 01 | A | Procurement | 50mm x 50mm x 1mm Stainless Steel Shims | 547908-04-0020-01A | 10 | g | g | g | 7900 | 0.020 | 0.200 | £ | 19.74 £ | 197.40 | RS | 204-4518 | https://uk.rs-online.com/web/p/pre-cut-shims/2044518 1D
547908 | 04 | ISO 4762 | - | - | Standard Part | M4x10 Socket Cap Bolt | 547908-04-ISO 4762--- | 20 | g | g | g | 7900 | 0.002 | 0.036 | £ | 0.04 £ | 0.80 | N/A | Supplied from MechSpace
547908 | 04 | ISO 7089 | - | - | Standard Part | M4 Flat Washer | 547908-04-ISO 7089--- | 8 | g | g | g | 7900 | 0.000 | 0.002 | £ | 0.02 £ | 0.16 | N/A | Supplied from MechSpace
547908 | 04 | ISO 4032 | - | - | Standard Part | M4 Hex Nut | 547908-04-ISO 4032--- | 16 | g | g | g | 7900 | 0.001 | 0.013 | £ | 0.06 £ | 0.96 | N/A | Supplied from MechSpace
547909 | 04 | ISO 4762 | - | - | Standard Part | M5 x12 Socket Cap Bolt | 547909-04-ISO 4762--- | 10 | g | g | g | 7900 | 0.003 | 0.030 | £ | 0.34 £ | 3.40 | N/A | Supplied from MechSpace
Total Mass | 12.608 | Total Cost | £ | 590.52
Part/Item Identification | Design Stage | Mass (kg) | Cost Details (₤) | Supply Chain Management
Project Bom Section UID Issue Revision Type Part Description Part Number Quantity | Layout 3D 2D | Density Mass Each Mass Total | Cost Each Cost Total (inc. VAT) (inc. VAT) | Company | Supplier Part Number Hyperlink Lead Time | Additional Info

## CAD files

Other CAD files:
CAD/Experimental Rig/fusion/Rig.f3z
CAD/Prototype/fusion/Extractor Prototype.f3z

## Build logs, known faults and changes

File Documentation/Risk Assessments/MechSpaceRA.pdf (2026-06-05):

Safety, Health, and Environmental risk assessment | Ref no. | STAFF ONLY

### Guidance: Complete sections 1.1-4.1 in order before writing summary

Review date

1 Fall from height 2 Fall on same level 3 Fall Down stairs/steps 4 Struck by moving object 5 Struck by falling object 6 Struck/trapped by something collapsed/overturned 7 Trapped between objects 8 Step on/struck against stationery object 9 Manual handling 10 Contact with tool/equipment/machinery 11 Contact with flying particle 12 Contact with low voltage electricity (<60V) 13 Contact with high voltage electricity (60-800V) 14 Contact with/exposure to air/water pressure 15 Contact with/exposure to heat/cold 16 Contact with/exposure to hazardous substance 17 Exposure to noise 18 Exposure to vibration 19 Exposure to rotating parts 20 Repetitive motion/action 21 Collision 22 Fire/flammable Atmosphere 23 Explosion 24 Assembling and Disassembling 25 Asphyxiation 26 Adverse weather conditions 27 Sharp objects 28 Oxygen enrichment 29 Exposure to fumes or dust 30 Exposure to Carbon or glass fibres 31 Exposure to Arc flash 32 Environmental threat 33 Other State

### 5.1 SIGN OFF

Name | Signature | Date

Academic

Name(s) | Ralf den Hartog | 21/1/2026

Staff Name

2.1 Hazard category What might cause harm? | 3.1 Hazard category | 3.2 Groups affected | 3.3 Nature of risk What might go wrong? | 3.4 Risk before controls T / I | 4.1 Preventative/control measures How do you stop it going wrong? | 4.2 Risk after controls T / I
P | O | M
9 Y | | | | Experimental rig will use aluminium profiles, in addition to an airbrush, mist generator and a conveyor belt. Together, these items can prove bulky and heavy to carry around. | T T | Divide components into groups, then place in bags/containers for transport. Team members to aid as necessary when moving parts around.
10 Y | | | | Use of saws and laser cutter for aluminium profile and acrylic panes. Injury possible if used improperly. | T T | Appropriate PPE and precaution when cutting profiles. MechSpace mentors notified when a laser cutting job is conducted.
11 | Y Y | | | Airbrush and mist generators used to simulate ink/water droplets and misting. Water used is dyed. | T | Stand far enough away to minimise risk of inhaling mist. Masks worn if necessary. No spraying paint is used. | T
12 Y | | | | Conveyor belt used to simulate printer substrate requires a power source. Electric motor and some wiring may be exposed to moisture from misting. | T | Internal electronics will not be modified and will be used conventionally. Motor and wiring will be wrapped in plastic. If insufficient, de-ionised water will be used | T
14 Y | | | | Air suction and/or induced air flow will be introduced to rig. Vacuum is used to provide the suction. Pressure of suction/induced airflow is low as it is a domestic vacuum. | T | The vacuum will only be turned on when fully secured and ready. | T
17 | Y | Y | | Conveyor belt generates a fair amount of noise when in use. Extraction system prototype uses a vacuum which is also expected to produce noise from suction/air flow. | T | Use earbuds when prolonged use is expected. Other people in area also notified of use and advised to wear earbuds. | T
24 | Y | | | Aluminium profiles could cut on its edges. | T | Approproate PPE worn when handling. | T Experimental rig is easily put together/broken down.
29 | Y | Y | | The generation of mist (small water droplets) may cause condensation and high humidity over extended operation. | I | Conduct testing in well-ventilated area. Masks worn if necessary. | T
13 Y | | | | Vacuum will require mains power. | T | Vacuum cabling will be kept neat to avoid tripping hazards. The vacuum electronics will not be modified and will be used conventionally. | T
19 Y | | | | Conveyor belt has rotating sprockets on the side. | T | Conveyor belt will be turned off when not in use. It is inside an enclosed box during use. | T

Person completing the
assessment
1.1 Activity/task | Aerosol Extraction System - 4th Year MEng Group Project

### 1.2 Relevant documents

1.3 Project/Lab location | MechSpace

S H E

Notes:
1. Where young persons or expectant mothers are involved in the activity, ensure that any additional controls are put in place in accordance with local procedures
2. Where a hazard is identified that is not listed, enter 33 in the Hazard Category column and describe under ‘Nature of risk’

Key: S Safety; H Health; E Environment; L Low risk; M Medium risk; H High risk; P People carrying out the activity/task;
O Others working in the vicinity; M Members of the public

T Tolerable

I Intolerable No injury, damage or env impact | Minor injury, damage or env impact | Major injury, damage or env impact | Fatality, building loss, catastrophic env impact
0 | 1 | 2 | 3
0
3 Almost no probability 3 Almost no probability 1 1

2 2

A small probability

A high probability Almost certain Quantifying the risk

L | L | L | L
L | L | M | H
L | M | H | H
L | H | H | H No injury, damage or env impact | Minor injury, damage or env impact | Major injury, damage or env impact | Fatality, building loss, catastrophic env impact
0 | 1 | 2 | 3
0
A small probability

A high probability Almost certain Quantifying the risk

L | L | L | L
L | L | M | H
L | M | H | H
L | H | H | H

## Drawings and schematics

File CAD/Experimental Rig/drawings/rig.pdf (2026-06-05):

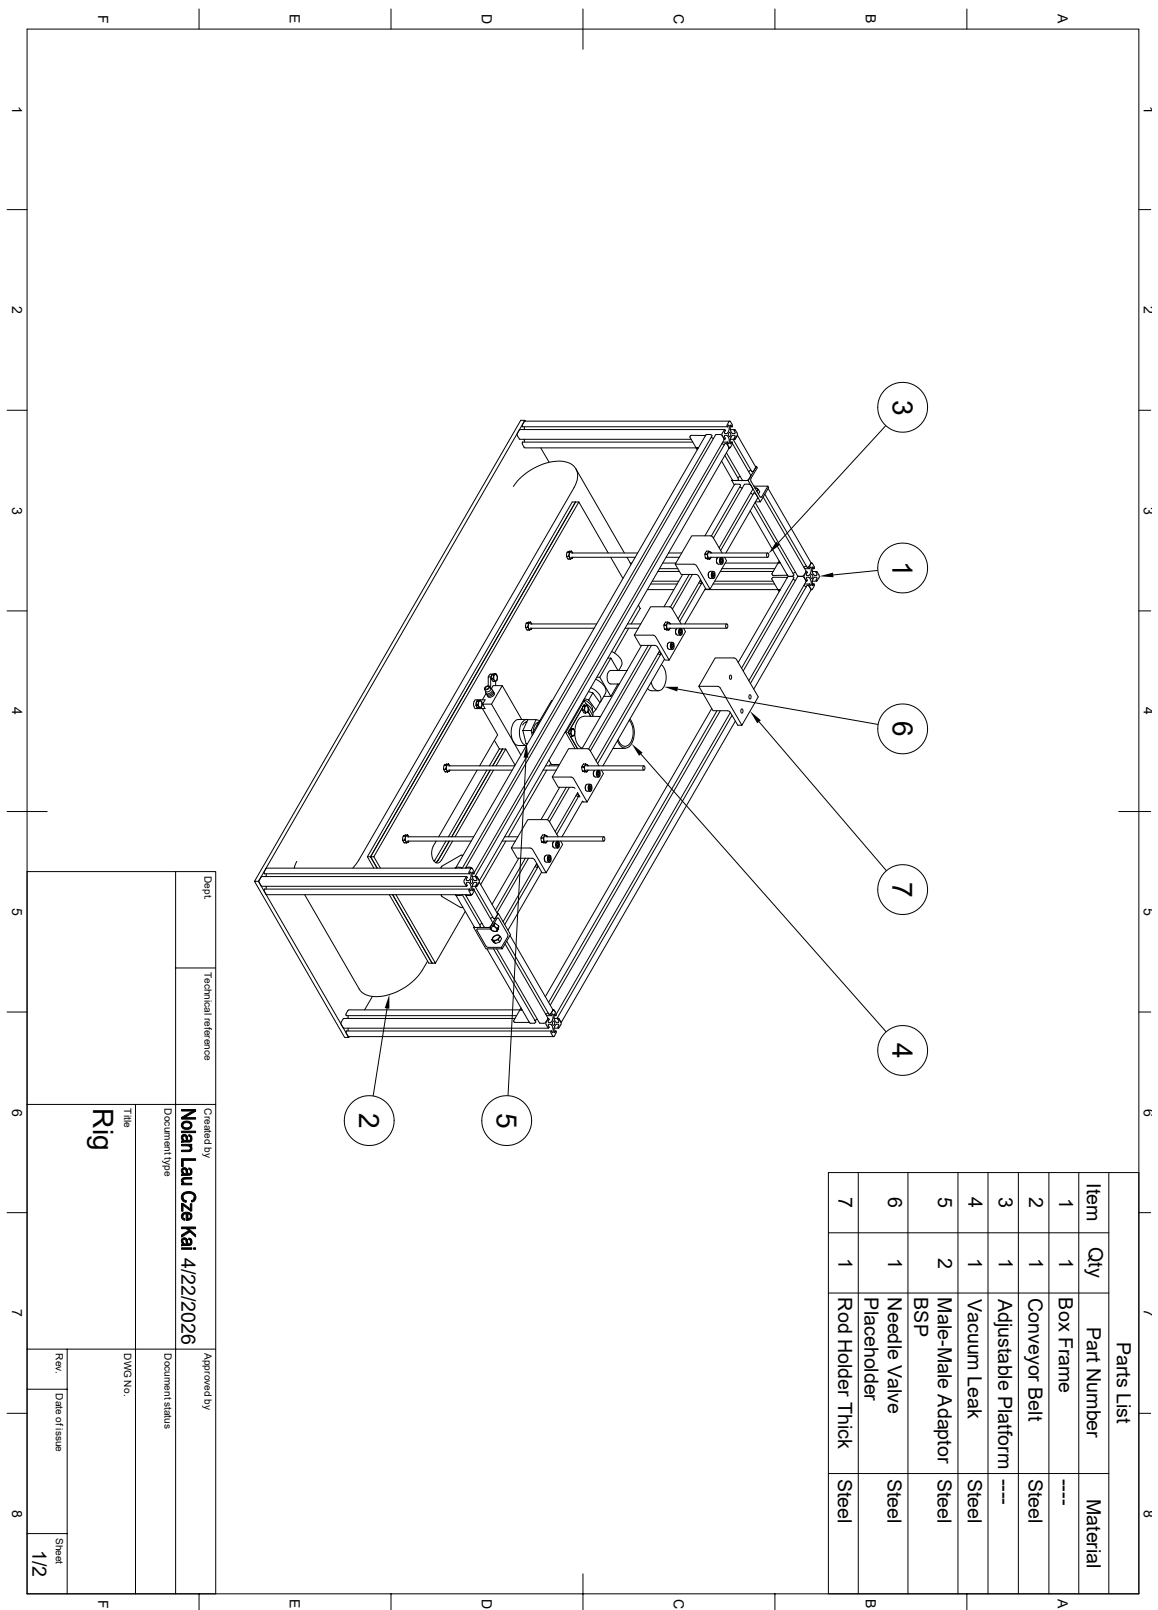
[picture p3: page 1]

1 A 2 3 4 5 6 7 8 1 2 3 4 5 6 7 8 FEDCB FEDCBA Dept. Technical reference Created by Approved by Title DWG No. Document type Document status Rev. Date of issue Sheet 4/22/2026 1/2 Rig Parts List Item Qty Part Number Material 1 1 Box Frame ---- 2 1 Conveyor Belt Steel 3 1 Adjustable Platform ---- 4 1 Vacuum Leak Steel 5 2 BSP Male-Male Adaptor Steel 6 1 Placeholder Needle Valve Steel 7 1 Rod Holder Thick Steel 25 3 1 6 7 4

210.39

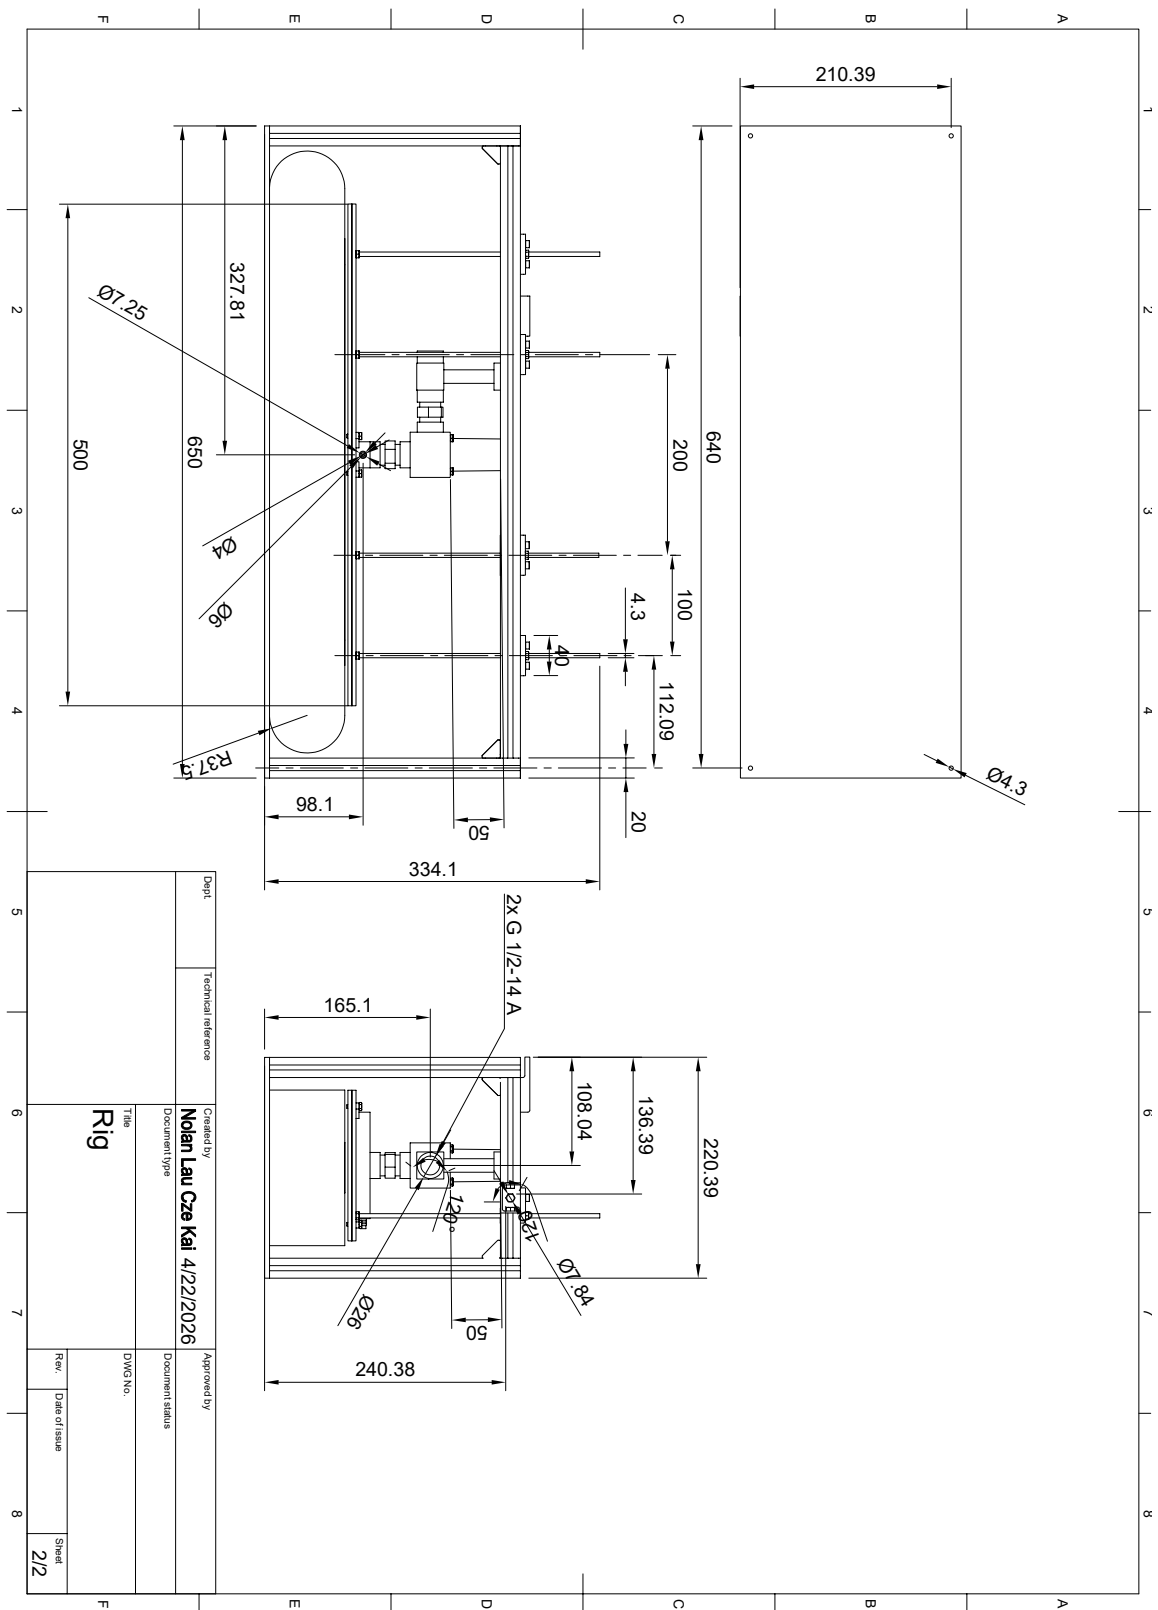
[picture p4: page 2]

1 A 2 3 4 5 6 7 8 1 2 3 4 5 6 7 8 FEDCB FEDCBA Dept. Technical reference Created by Approved by Title DWG No. Document type Document status Rev. Date of issue Sheet 4/22/2026 2/2 Rig 650

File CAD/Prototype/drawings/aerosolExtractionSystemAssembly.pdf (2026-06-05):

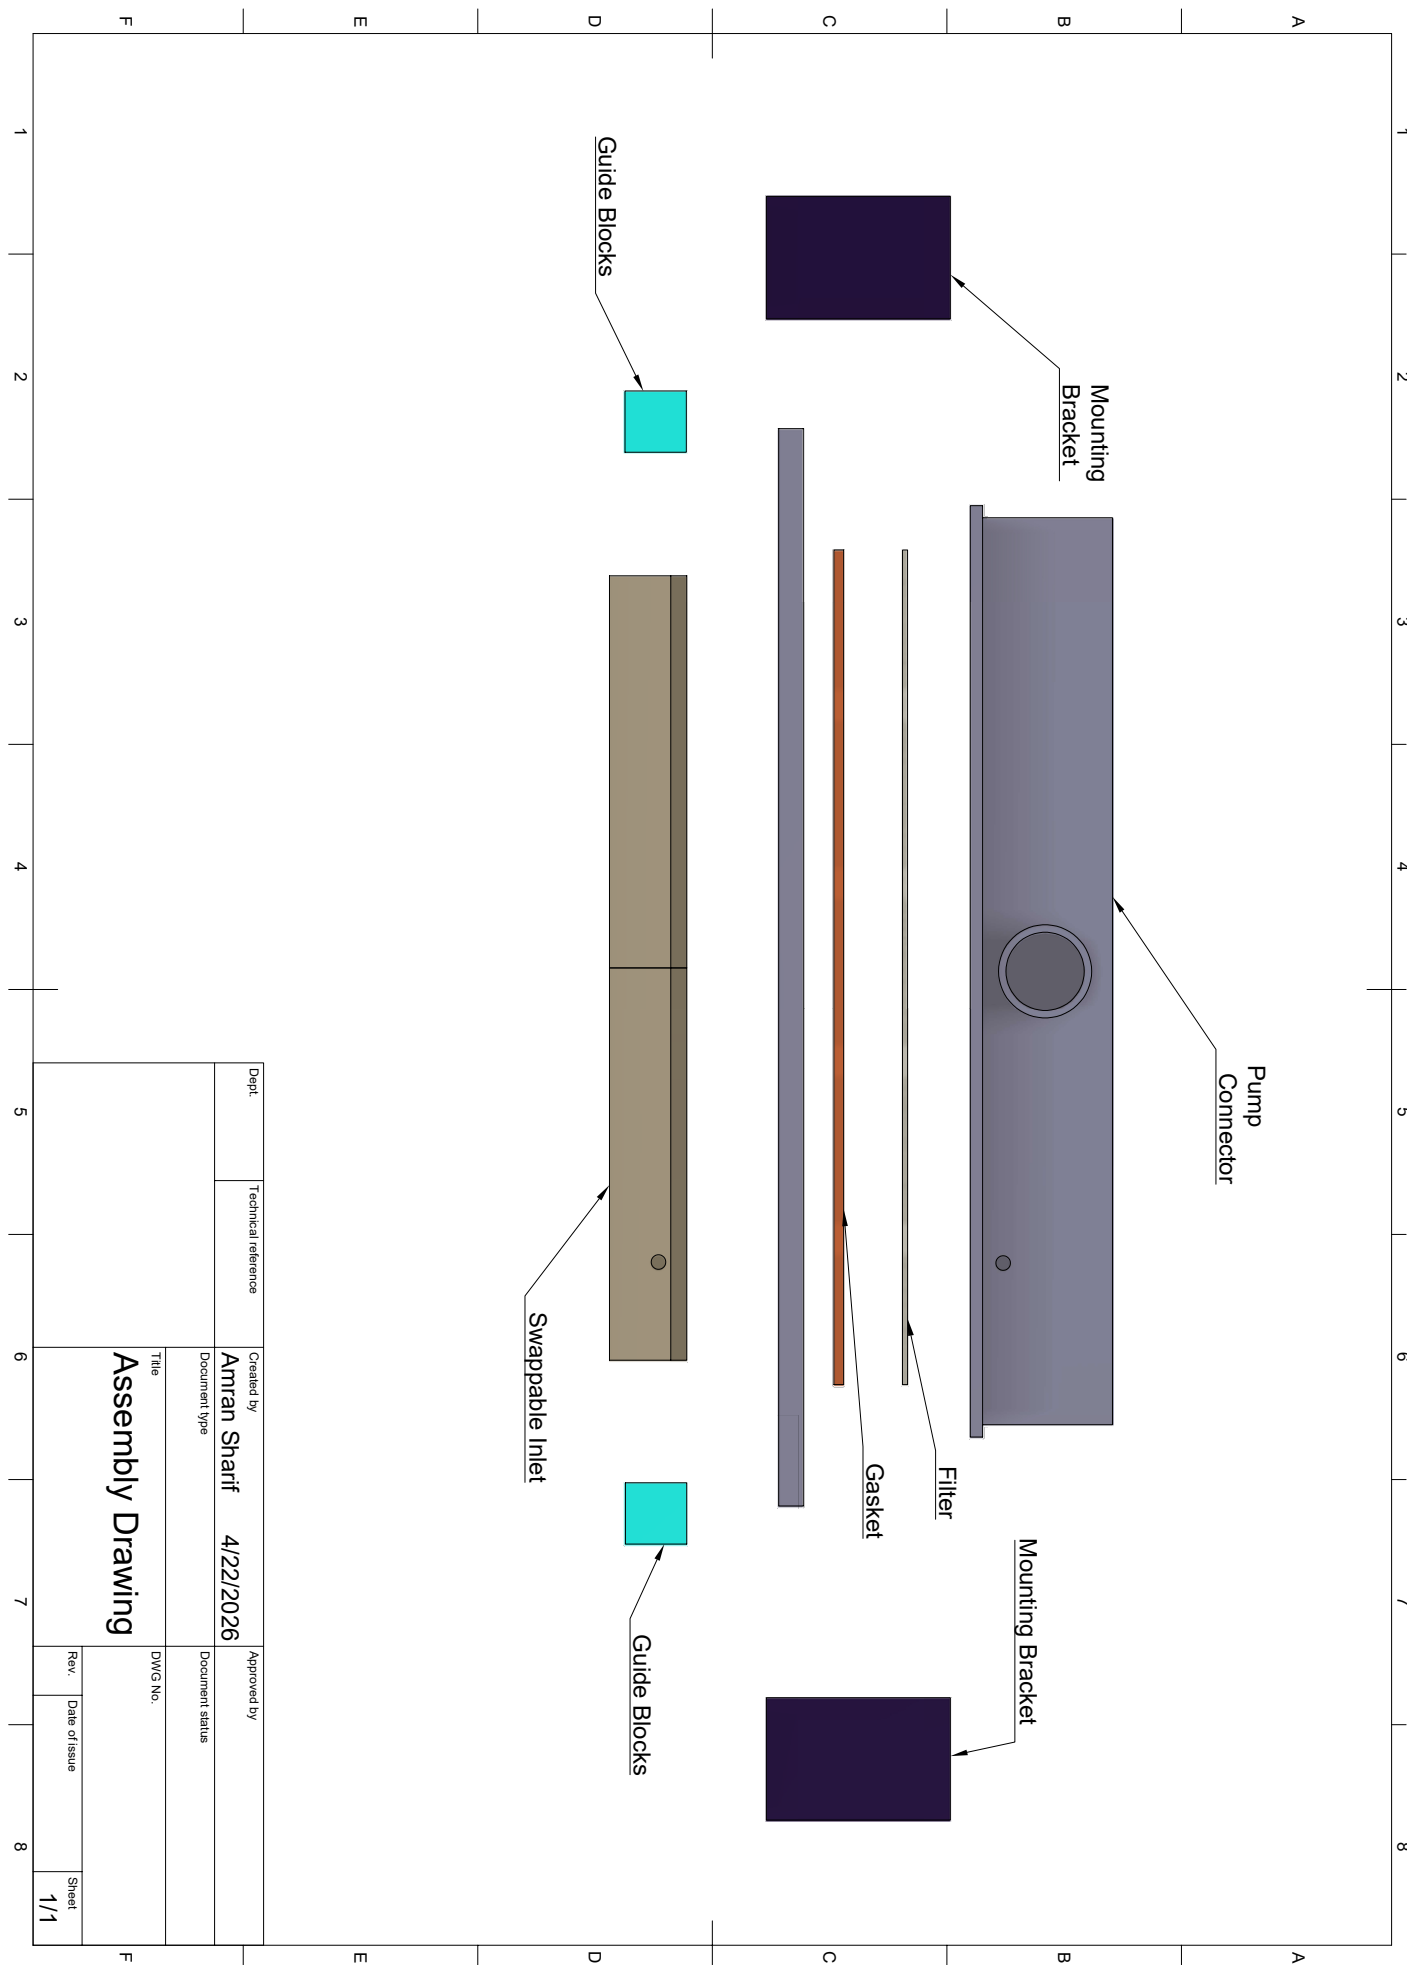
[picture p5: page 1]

1 A 2 3 4 5 6 7 8 1 2 3 4 5 6 7 8 FEDCB FEDCBA Dept. Technical reference Created by Approved by Title DWG No. Document type Document status Rev. Date of issue Sheet 4/22/2026 1/1 Assembly Drawing Amran Sharif Connector Pump Bracket Mounting Mounting Bracket Gasket Filter Swappable Inlet Guide Blocks Guide Blocks

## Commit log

2026-06-04 Uploaded Code Handover Document
    The code handover document covers the computational framework and code used in OpenFoam for the MECH0073 Aerosol Extraction System Capstone Project.
2026-06-05 Added Documentation, CAD, and Electronics
    [Extractor Prototype.f3z, Rig.f3z]
